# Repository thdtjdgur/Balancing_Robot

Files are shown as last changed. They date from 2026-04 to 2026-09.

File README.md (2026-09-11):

# ESP32 밸런싱로봇

<p align="center">
  
  
  
  
</p>

<p align="center">
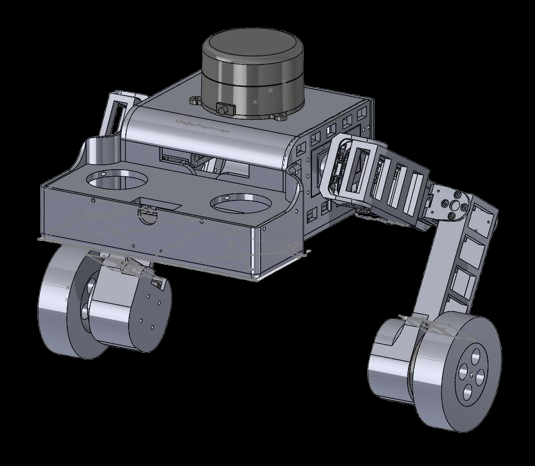
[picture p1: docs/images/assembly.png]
SolidWorks assembly render
  
</p>

`ESP32-S3` 기반 2륜 밸런싱로봇의 제어 코드와 검증 자료를 정리한 저장소이다.

기지국에서 전달한 GPS 웨이포인트를 순서대로 따라가며 사람을 수색하는 구조를 목표로 한다. 로봇은 현재 위치와 목표점을 로컬 `x/y` 좌표로 변환한다. `MPPI` 제어기는 이 좌표를 바탕으로 목표 속도와 목표 각속도를 계산한다. 이 명령은 모터에 바로 전달되지 않는다. 속도, 자세, 요 제어용 `PID`를 거친 뒤 왼쪽과 오른쪽 바퀴의 `Vq` 명령으로 나뉜다. 마지막으로 엔코더 각도를 이용한 역 DQ 변환을 통해 BLDC 3상 전압으로 출력한다.

실물 로봇을 바로 튜닝하지 않는다. MATLAB에서 MPPI 명령 생성 로직을 먼저 확인한다. 이후 `SILS`와 `HILS`로 PID 제어 흐름과 ESP32 펌웨어 통신 구조를 검증한다. 마지막 단계에서 실물 로봇으로 외란 복귀, 목표 속도 추종, 블루투스 수동 조작을 확인한다.

---

## 전체 제어 흐름

```text
기지국 GPS 웨이포인트
-> GNSS 로컬 좌표 변환
-> 웨이포인트 관리자
-> MPPI 제어기: v_ref, w_ref 생성
-> 속도 PID: 목표 피치 생성
-> 피치 PID + 요 제어: 좌우 Vq 생성
-> 엔코더 각도 보정
-> 역 DQ 변환
-> BLDC 3상 전압 출력
```

MPPI는 목표점까지 이동하기 위한 상위 명령을 만든다. PID는 로봇이 넘어지지 않도록 속도 명령을 자세 제어로 바꾼다. DQ 변환은 계산된 전압 명령을 실제 BLDC 모터가 사용할 3상 전압으로 바꾸는 단계이다.

---

## 구현 범위

- ESP32-S3 기반 밸런싱로봇 제어 루프를 구현한다.
- 기지국 GPS 웨이포인트를 순서대로 따라가는 GNSS 미션 레이어를 구성한다.
- MPPI 제어기로 목표 속도와 목표 각속도를 생성한다.
- MATLAB MPPI 시뮬레이션으로 펌웨어 적용 전 명령 생성 로직을 확인한다.
- 속도, 피치, 요 제어가 이어지는 캐스케이드 PID 구조를 구성한다.
- 엔코더 기반 속도 추정과 BLDC 3상 전압 생성을 구현한다.
- 블루투스 조이스틱 입력으로 실물 밸런싱과 수동 조작을 확인한다.
- MATLAB/Simulink HILS를 구성해 실제 ESP32 펌웨어와 가상 모델의 데이터 교환을 검증한다.
- RX-28 관절 액추에이터와 YDLIDAR G2 확장 코드를 함께 정리한다.

---

## 제어 구조

## 1. MPPI: 웨이포인트를 속도와 각속도 명령으로 바꾸는 상위 제어기

### 역할

MPPI는 현재 위치, 목표점, 장애물 정보를 받아 여러 개의 미래 명령열을 만든다. 명령열 하나는 `v_ref`와 `w_ref`의 시간 순서이다. 각 명령열을 적용했을 때 로봇이 어디로 움직일지 예측하고, 목표점에 가까우면서 장애물을 피하는 명령열에 높은 가중치를 준다.

마지막에는 모든 후보 명령열을 가중 평균한다. 실제 로봇에는 그중 첫 번째 명령만 전달한다. 다음 제어 주기에서 다시 샘플링하므로, 로봇은 매 순간 새 센서값을 반영해 경로를 다시 고른다.

### ESP32 펌웨어 구성

ESP32 쪽 MPPI 코드는 `SoftWare/Gnss_Mppi`에 들어 있다.

- `gnss.c`: 현재 GNSS 위치와 목표 웨이포인트를 로컬 `x/y` 좌표로 변환한다.
- `waypoint.c`: 기지국에서 받은 웨이포인트를 순서대로 목표점에 넣는다.
- `mppi.c`: 후보 명령열을 만들고, 예측 상태를 계산한 뒤 최종 `v_ref`, `w_ref`를 선택한다.
- `cost.c`: 목표점 오차, 장애물 거리, 입력 크기, 입력 변화량을 비용으로 계산한다.
- `lidar.c`: 라이다 거리 데이터를 받아 장애물 정보를 구성한다.

### 장애물 처리

실제 로봇은 라이다 360도를 `24`개 섹터로 나눠 본다. 한 섹터 안에 장애물이 여러 개 들어오면 가장 가까운 장애물 하나만 대표값으로 저장한다. MPPI 비용 계산에서는 이 섹터 거리와 각도를 월드 좌표의 장애물 위치로 바꾼다. 예측된 로봇 위치가 안전거리 안으로 들어가면 장애물 비용이 커진다.

MATLAB 시뮬레이션에서는 장애물을 절대좌표에 직접 배치한다. 입력 방식만 다를 뿐, 예측 로봇 위치와 장애물 위치 사이의 거리로 비용을 계산한다는 점은 같다.

### 계산 순서

1. 이전 최적 명령열을 한 칸 앞으로 당겨 현재 샘플링의 기준 명령열로 사용한다.
2. 기준 명령열에 랜덤 노이즈를 더해 후보 명령열을 만든다.
3. 후보 명령열마다 미래 로봇 위치와 방향을 예측한다.
4. 목표점 비용, 장애물 비용, 입력 비용, 입력 변화 비용을 누적한다.
5. 비용을 `exp(-(J_i - J_min) / lambda)` 형태의 MPPI 가중치로 바꾼다.
6. 가중 평균으로 최종 명령열을 만들고 첫 번째 입력만 적용한다.

### ESP32 적용 파라미터

실제 펌웨어에서는 ESP32 계산량을 고려해 짧은 예측 구간을 사용한다.

- 제어 주기: `dt = 0.1 s`
- 예측 스텝: `horizon = 6`
- 후보 명령열: `num_samples = 64`
- 속도 범위: `-0.5 m/s` ~ `0.5 m/s`
- 각속도 범위: `-1.2 rad/s` ~ `1.2 rad/s`
- MPPI 온도 파라미터: `lambda = 10.0`
- 장애물 안전거리: `0.5 m`

### MATLAB 사전검증

펌웨어에 넣기 전, MATLAB에서 같은 구조의 MPPI를 먼저 돌렸다. 하드웨어를 그대로 복제하려는 목적은 아니다. 목표점과 장애물이 있을 때 후보 명령열이 충분히 퍼지는지, 장애물 비용이 회피 방향에 영향을 주는지, 최종 가중 평균 궤적이 목표점 방향으로 이어지는지를 보기 위한 단계이다.

시뮬레이션 코드는 `SoftWare/Mppi_matlab_simulation`에 정리했다.

- `main.m`: 시작점, 목표점, 장애물, 반복 루프를 설정한다.
- `mppi/init_mppi_params.m`: MPPI 파라미터와 비용 가중치를 설정한다.
- `mppi/mppi_step.m`: 후보 명령열 생성, 비용 계산, 가중 평균 계산을 수행한다.
- `cost/calc_total_cost.m`: 목표점, 장애물, 입력, 부드러움 비용을 계산한다.
- `sim/draw_sim.m`: 로봇 이동 경로, 장애물, 목표점, 후보 궤적을 그린다.

[MPPI MATLAB 시뮬레이션 영상](docs/videos/mppi_test.mp4)

MATLAB 검증에서 사용한 주요 설정은 다음과 같다.

- 제어 주기: `dt = 0.1 s`
- 예측 스텝: `horizon = 30`
- 예측 시간: `3.0 s`
- 후보 명령열: `num_samples = 64`
- 속도 범위: `-0.5 m/s` ~ `0.5 m/s`
- 각속도 범위: `-1.2 rad/s` ~ `1.2 rad/s`
- MPPI 온도 파라미터: `lambda = 10.0`
- 이전 최적 명령열이 있을 때 노이즈: `v_amp = 0.30`, `w_amp = 0.80`
- 첫 탐색 노이즈: `v_amp = 0.40`, `w_amp = 0.90`

### 비용 함수

MATLAB 비용 함수는 아래 구조로 계산한다.

```text
total_cost =
  goal_cost
  + obstacle_cost
  + input_cost
  + smooth_cost
```

검증 당시 비용 가중치는 다음과 같다.

- 목표점 x축 가중치: `weight_goal_x = 1.5`
- 목표점 y축 가중치: `weight_goal_y = 1.5`
- 장애물 비용 가중치: `weight_obstacle = 120.0`
- 속도 입력 비용 가중치: `weight_input_v = 0.1`
- 각속도 입력 비용 가중치: `weight_input_w = 0.1`
- 속도 변화 비용 가중치: `weight_smooth_v = 0.3`
- 각속도 변화 비용 가중치: `weight_smooth_w = 0.3`
- 장애물 안전거리: `obs_safe_dist = 1.0 m`

## 2. PID: MPPI 명령을 넘어지지 않는 자세 제어로 바꾸는 층

### 역할

MPPI가 만든 `v_ref`와 `w_ref`는 모터에 바로 넣지 않는다. 밸런싱로봇은 목표 속도를 따라가면서 몸체 각도도 계속 잡아야 한다. 그래서 목표 속도는 먼저 목표 피치가 되고, 피치 제어 결과가 좌우 바퀴 전압 명령으로 이어진다.

### 제어 흐름

```text
targetvel_vel
-> 속도 PID
-> target_pitch
-> 피치 PID
-> 균형 유지용 출력
-> yaw 보정값과 합성
-> Vq_left, Vq_right
```

속도 PID는 목표 속도와 현재 속도의 차이로 몸체가 얼마나 기울어야 하는지 정한다. 피치 PID는 현재 피치가 목표 피치에 맞도록 균형 출력을 만든다. 요 제어는 왼쪽과 오른쪽 바퀴 명령에 차이를 만들어 회전 방향을 잡는다.

### SILS

SILS에서는 실제 하드웨어 없이 제어 응답을 먼저 본다. 응답이 발산하는지, 목표 속도나 외란에 대해 로봇 자세가 다시 안정되는지 확인한다.

<p align="center">
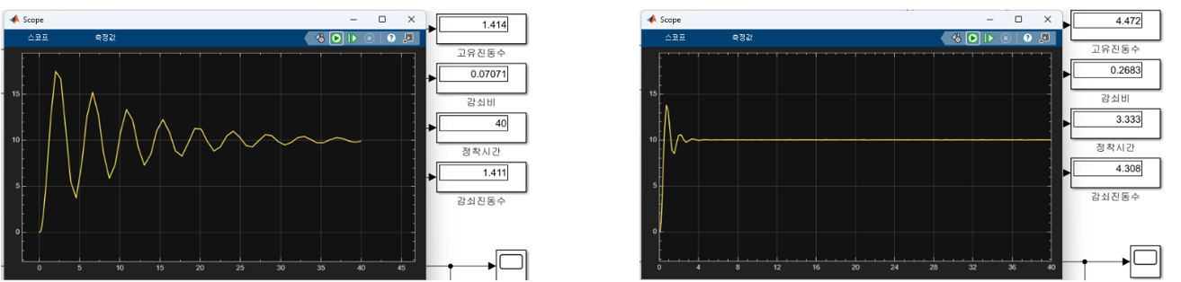
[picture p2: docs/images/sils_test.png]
SILS test result
  
</p>

### HILS 통신 구조

SILS 이후에는 HILS를 구성한다. MATLAB/Simulink가 가상 센서 역할을 하고, 실제 ESP32 펌웨어가 제어 계산을 맡는다. 실물 로봇에 올리기 전에 데이터 패킷, 제어 주기, 반환 전압값이 의도대로 이어지는지 확인하는 단계이다.

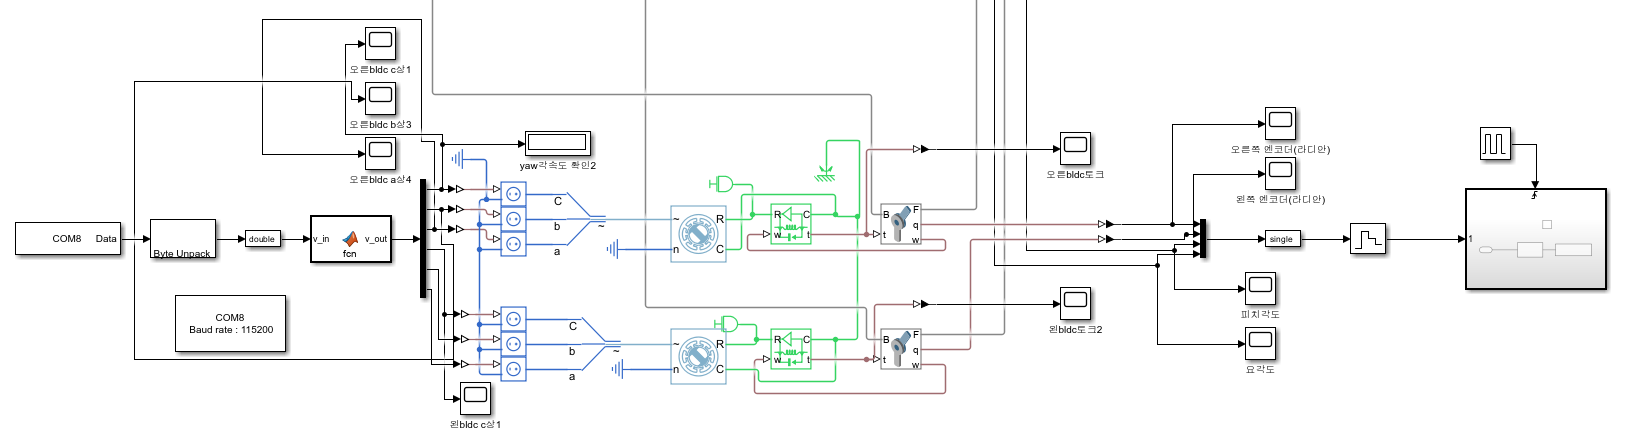
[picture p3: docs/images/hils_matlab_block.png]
HILS block diagram


PC와 ESP32는 `CP2102 USB-to-TTL` 모듈로 연결한다. ESP32는 `UART2`를 사용하고, `TX=GPIO17`, `RX=GPIO18`에 연결한다.

MATLAB에서 ESP32로 보내는 값은 오른쪽 엔코더, 왼쪽 엔코더, pitch, yaw이다. 각 값은 `single(float)`이므로 4바이트이다. 한 번 보낼 때 `4개 * 4바이트 = 16바이트`가 된다.

ESP32는 받은 센서값으로 제어를 계산하고, 왼쪽과 오른쪽 BLDC의 3상 전압을 MATLAB으로 돌려보낸다. 반환값은 총 6개 float이므로 `6개 * 4바이트 = 24바이트`이다. Simulink에서는 `Serial Receive`로 24바이트를 받고, `Byte Unpack`으로 6개의 `single(float)` 값으로 복원한다.

### 보레이트 계산

[HILS 구조 참고 PDF](docs/references/hils_flow.pdf) 기준으로 MATLAB에서 ESP32로 보내는 센서 패킷은 1kHz 주기로 들어온다.

```text
16 byte/packet * 1000 packet/s = 16000 byte/s
```

UART는 일반적으로 8비트 데이터 앞뒤에 start bit와 stop bit가 붙는다. 즉 1바이트를 보내려면 실제 라인에서는 10비트가 필요하다.

```text
16000 byte/s * 10 bit/byte = 160000 bit/s
```

ESP32에서 MATLAB으로 돌아오는 값은 24바이트 패킷이다. 같은 1kHz 기준으로 보면 아래와 같다.

```text
24 byte/packet * 1000 packet/s * 10 bit/byte = 240000 bit/s
```

양방향 모두 같은 UART 설정을 쓰므로 더 큰 쪽인 `240000 bps`보다 높은 보레이트가 필요하다. 그래서 `921600 bps`를 사용했다. 계산상 필요한 속도보다 약 3.8배 여유가 있고, HILS에서 1kHz 데이터 교환을 할 때 패킷 지연 여지를 줄일 수 있다.

### 속도 추정

엔코더 각도는 `1 kHz`로 읽지만 속도 추정은 매 주기마다 갱신하지 않는다. `1 ms` 차분에서는 각도 변화량이 너무 작다. 작은 엔코더 흔들림도 큰 속도 스파이크처럼 계산될 수 있다.

그래서 엔코더 각도는 계속 `1 kHz`로 샘플링하고, 속도 추정만 `10`회마다 한 번 갱신한다. 실제 속도 추정 주기는 `10 ms`이다. `+/-pi` 경계에서 각도 차이가 튀지 않도록 언랩 처리를 넣고, `0.5 / 0.5` 저역통과 필터로 남은 노이즈를 줄인다.

### RTOS 스케줄링

실물 로봇에서는 센서 요청과 모터 출력의 타이밍이 바로 진동으로 이어졌다. 엔코더 경로는 GPTimer `1 MHz` 해상도와 `alarm_count = 1000` 설정으로 `1 ms`마다 동작한다. SPI 엔코더 읽기가 끝나면 `spi_post_callback()`에서 `encoder_sem`을 깨운다. `motor_control_task`는 새 엔코더 값이 준비됐을 때만 모터 전압 계산을 수행한다.

IMU 경로는 `IMU_ALARM_COUNT = 5000`으로 `5 ms`, 즉 `200 Hz`마다 동작한다. 모터 제어 태스크는 우선순위 `5`, RX-28 태스크는 우선순위 `4`로 분리한다. 엔코더 기반 모터 출력 경로를 더 높은 우선순위로 두면서 균형 제어의 시간 흔들림을 줄인다.

### 조이스틱 입력

블루투스 조이스틱 입력은 자동 수색 미션의 주 경로가 아니라 실물 밸런싱 테스트용 입력이다. `hc06.c`는 `S,x,y,diff,E` 형식의 패킷을 파싱한다. 조이스틱이 중앙 근처에 있으면 목표 속도와 요 명령을 0으로 만든다. 일정 크기 이상 움직이면 전진 속도와 회전 명령을 생성한다.

이 입력으로 실물 로봇이 넘어지지 않고 전진, 정지, 회전을 수행하는지 확인한다.

### RX-28 관절 제어

RX-28 관절 제어는 카메라 흔들림을 줄이기 위한 확장 구조이다. IMU에서 측정한 `roll` 값을 기준으로 보정 길이 `roll_adj_mm`를 만든다. 좌우 다리 높이를 다르게 계산해 골반과 무릎 RX-28 목표 위치로 변환한다.

`rx28.c`는 미리 계산한 다리 높이 테이블을 이용해 목표 높이에 맞는 관절 값을 보간한다. 바퀴 제어만으로 처리하기 어려운 좌우 기울어짐을 관절 쪽에서 보정하는 구조이다.

## 3. DQ 변환: Vq 명령을 BLDC 3상 전압으로 바꾸는 층

### 역할

PID를 거쳐 나온 최종 명령은 왼쪽과 오른쪽 바퀴의 `Vq_left`, `Vq_right`이다. 이 값은 BLDC 모터의 q축 전압 명령이다. 실제 모터에는 3상 전압 `Va`, `Vb`, `Vc`가 들어가야 한다. 그래서 엔코더 각도를 이용해 역 Park 변환과 Clarke 변환을 수행한다.

### SPI 타이밍 문제

DQ 변환에서 가장 먼저 맞춰야 했던 값은 엔코더 각도이다. AS5048A 엔코더는 SPI로 16비트 데이터를 보낸다. 이때 CSn을 낮춘 뒤 첫 번째 클럭 상승까지 필요한 최소 시간이 데이터시트 기준 `tL = 350 ns`이다.

<p align="center">
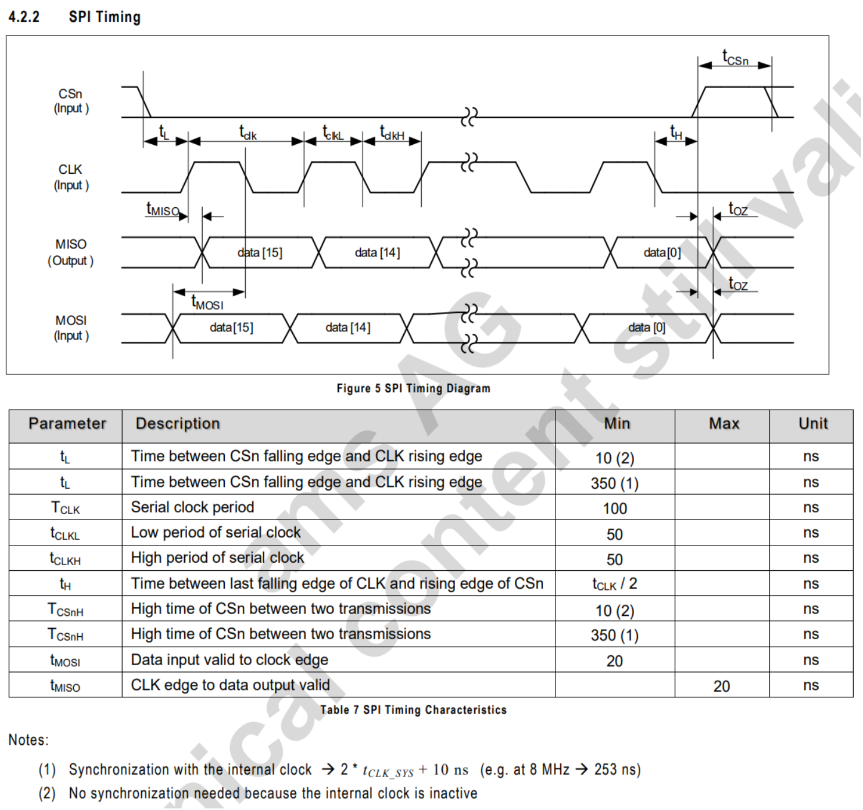
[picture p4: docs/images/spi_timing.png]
AS5048A SPI timing
  
</p>

초기에는 CSn을 낮춘 직후 바로 데이터를 읽으면서 16비트 저장 위치가 한 칸씩 밀렸다. 첫 번째 클럭이 아직 생성되기 전인데 MCU가 `data[15]` 자리를 읽으려 하면, 그 위치에는 유효한 센서 데이터가 들어오지 않는다. 결과적으로 15번째 비트에는 의미 없는 값이 들어가고, 14번째 비트에는 원래 `data15`, 13번째 비트에는 원래 `data14`가 들어가는 식으로 데이터가 오른쪽으로 밀린다.

MCU는 하위 14비트를 각도 원시값으로 해석한다. 당시에는 에러 비트가 항상 1처럼 보였고, 밀린 데이터 때문에 각도 원시값의 상위 비트가 계속 켜지는 현상이 발생했다. 그 결과 각도값에 180도가 더해진 것처럼 해석되어 `180~360 deg` 구간 위주로 값이 나왔다.

해결은 CSn 이후 첫 클럭까지의 대기 시간을 SPI 설정으로 보장하는 방식이다. 현재 엔코더 SPI 클럭은 `10 MHz`이고, 한 클럭은 `100 ns`이다. `encoder.c`에서 `.cs_ena_pretrans = 4`로 설정해 약 `400 ns`를 기다린다. 이 값은 필요한 `350 ns`보다 길기 때문에 첫 번째 클럭 전에 데이터가 밀리는 문제를 줄인다.

### 전기각 오프셋

엔코더 각도는 전기각 오프셋도 맞춰야 한다. `d = 상수`, `q = 0`으로 두면 토크를 만드는 q축 명령은 0이 된다. 대신 회전자를 고정시키는 d축 성분이 상수로 들어가므로 회전자가 한 위치에 고정된다. 이때의 엔코더 값은 전기적 각도 0도에 해당하는 기계적 기준값이다. 이 값이 오프셋이다.

엔코더가 그 순간 0을 읽는 것은 아니다. 그래서 실제 제어에서는 읽어온 엔코더 각도에서 오프셋 각도를 뺀 뒤 극쌍수를 곱해 전기각을 계산한다.

```text
electrical_angle = (measured_encoder_angle - offset_angle) * pole_pairs
```

현재 코드에서는 `GM4108H-120T` 모터의 극쌍수 `11`을 사용한다. 왼쪽 바퀴 오프셋은 `2.7756 rad`, 오른쪽 바퀴 오프셋은 `1.6345 rad`이다.

### 3상 전압 생성

전기각을 계산한 뒤 `Vd = 0`, `Vq = Vq_left/right`를 기준으로 역 Park 변환을 수행한다. 이후 Clarke 변환으로 `Va`, `Vb`, `Vc`를 만든다. 이 3상 전압이 MCPWM 출력으로 전달되어 BLDC 모터를 구동한다.

---

## 실물 테스트

HILS 이후에는 실물 로봇으로 외란 복귀, 위치 유지, 블루투스 주행을 확인한다. 이 단계에서는 제어 알고리즘 자체뿐 아니라 태스크 우선순위, 엔코더 속도 추정 주기, 조이스틱 입력이 실제 균형 유지에 어떤 영향을 주는지 함께 확인한다.

<p align="center">
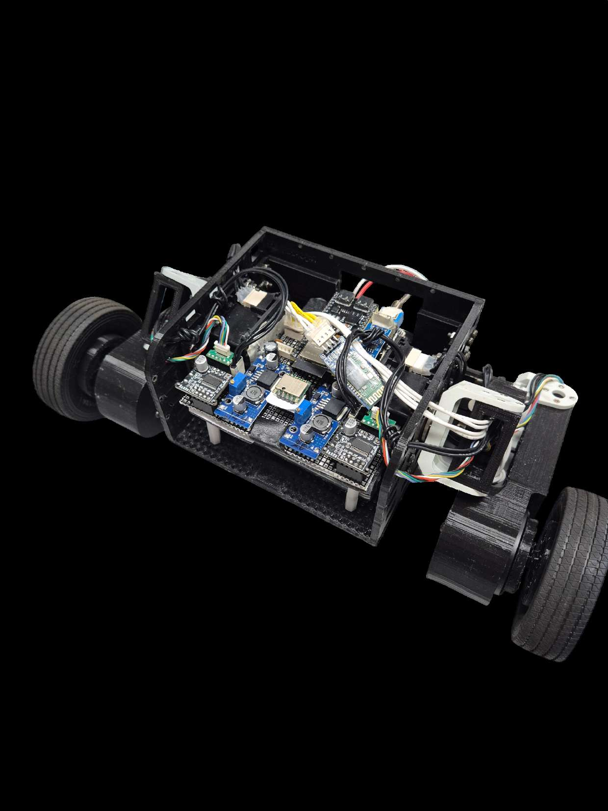
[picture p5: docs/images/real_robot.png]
real robot
  
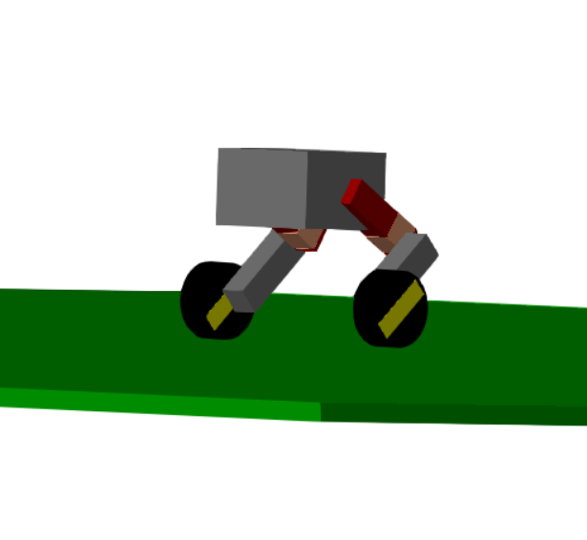
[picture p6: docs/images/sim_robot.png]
simulation robot
  
</p>

실물 테스트에서 중점적으로 보는 항목은 다음과 같다.

- 외부에서 밀었을 때 로봇이 다시 자세를 회복하는지 확인한다.
- 목표 속도를 줄 때 몸체가 자연스럽게 기울어지며 따라가는지 확인한다.
- 블루투스 조이스틱으로 전진, 정지, 회전을 입력해도 밸런싱이 깨지지 않는지 확인한다.

---

## 검증 자료

GitHub README에서는 mp4가 항상 바로 재생되지 않기 때문에 영상은 링크로 정리한다.

- [MPPI MATLAB 시뮬레이션](docs/videos/mppi_test.mp4)
- [HILS 테스트 영상](docs/videos/hils_test.mp4)
- [SILS yaw 테스트 영상](docs/videos/sils_yaw_test.mp4)
- [SILS 목표 속도 테스트 영상](docs/videos/sils_target_velocity_test.mp4)
- [SILS 외란 복귀 테스트](docs/videos/sils_disturbance_rejection.mp4)
- [실물 외란 복귀 테스트](docs/videos/real_world_disturbance_rejection.mp4)
- [실물 위치 유지 테스트](docs/videos/real_world_hold_position_after_disturbance.mp4)
- [실물 블루투스 조작 테스트](docs/videos/real_world_bluetooth_control.mp4)
- [BLDC 역 DQ 제어 영상 Q=1](docs/videos/inverse_dq_control_q1.mp4)
- [BLDC 역 DQ 제어 영상 Q=4](docs/videos/inverse_dq_control_q4.mp4)
- [HILS 구조 참고 PDF](docs/references/hils_flow.pdf)
- [밸런싱로봇 정리 PDF](docs/images/balancing_robot_evidence.pdf)

---

## 하드웨어 구성

최종 실물 테스트 기준 주요 부품은 다음과 같다.

- 메인 컨트롤러: `ESP32-S3-WROOM-1 N16R8`
- 휠 모터: `GM4108H-120T` BLDC 모터 2개
- 휠 모터 드라이버: `MKS SimpleFOC MINI` 2개
- 휠 엔코더: `AS5048A` 2개
- 관절 액추에이터: `Dynamixel RX-28` 4개
- 통신 변환기: `MAX485 TTL to RS-485`
- IMU: `WT901`
- 블루투스 모듈: `HC-06`
- HILS UART 브리지: `CP2102 USB-to-TTL`
- 전원: `3S LiPo battery`, `XL6009` 승압 모듈

검토 또는 확장용으로 사용한 부품은 다음과 같다.

- `U2D2`
- `U2D2 Power Hub`
- `YDLIDAR G2`
- `MPU6050`

최종 밸런싱 테스트에서 실제로 사용한 IMU는 `WT901`이다.

---

## 파일 구조

- `SoftWare/Physical_operation_code/`: 실물 밸런싱로봇용 ESP-IDF 펌웨어이다.
- `SoftWare/Physical_operation_code/app_main.c`: 태스크 생성, 세마포어 대기, PID 제어 통합을 담당한다.
- `SoftWare/Physical_operation_code/encoder.c`: 엔코더 SPI 읽기, 속도 추정, 전기각 계산, 역 DQ 변환, 3상 전압 출력을 담당한다.
- `SoftWare/Physical_operation_code/imu.c`: WT901 IMU 값을 읽고 200 Hz 상태 갱신 경로를 구성한다.
- `SoftWare/Physical_operation_code/pid.c`: 속도, 피치, 요, 롤 제어에 사용하는 PID 계산을 담당한다.
- `SoftWare/Physical_operation_code/pwm.c`: MCPWM 기반 모터 전압 출력을 담당한다.
- `SoftWare/Physical_operation_code/hc06.c`: 블루투스 조이스틱 입력을 파싱한다.
- `SoftWare/Physical_operation_code/rx28.c`: RX-28 관절 제어와 roll 기반 보정 구조를 담당한다.
- `SoftWare/Physical_operation_code/lidar.c`: YDLIDAR G2 확장 코드를 포함한다.
- `SoftWare/Gnss_Mppi/`: GNSS 웨이포인트, 24섹터 라이다 장애물, MPPI 명령 생성이 포함된 펌웨어 변형이다.
- `SoftWare/Mppi_matlab_simulation/`: ESP32 MPPI 적용 전 MATLAB에서 명령 생성 로직을 검증한 코드이다.
- `SoftWare/hils_test_code/`: MATLAB/Simulink HILS 검증용 ESP-IDF 프로젝트이다.

---

## 빌드 방법

이 프로젝트는 `ESP-IDF` 기준으로 작성한다.

실물 로봇 코드는 `SoftWare/Physical_operation_code`에서 빌드한다.

```bash
idf.py build
```

보드에 플래시한다.

```bash
idf.py -p (PORT) flash
```

필요하면 시리얼 모니터를 연다.

```bash
idf.py -p (PORT) monitor
```

HILS용 코드를 사용할 때는 `SoftWare/hils_test_code`로 이동한 뒤 같은 `idf.py` 흐름을 사용한다. GNSS와 MPPI가 포함된 자율 주행용 코드는 `SoftWare/Gnss_Mppi`에서 확인한다.

---

## 한 줄 요약

GPS 웨이포인트 기반 수색 로봇을 만들기 위해 MPPI로 상위 이동 명령을 만들고, PID로 균형을 유지하며, 엔코더 보정 기반 역 DQ 변환으로 BLDC 모터를 구동한 ESP32 밸런싱로봇 프로젝트이다.

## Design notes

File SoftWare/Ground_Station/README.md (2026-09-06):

# Drone GUI Ground Station

`guitest.py`는 지도/웨이포인트 UI를 제공하고, `keytest.py`는 NTRIP 수신과
TTGO 시리얼 링크의 2초 반이중 송신 주기를 관리합니다.

## RTCM 정책

- 허용 타입: `1004`, `1006`, `1012`, `1230`
- 타입마다 최신 정상 프레임 하나만 보관
- 동일 타입의 새 프레임은 이전 미전송 프레임을 교체
- 2초마다 신선한 `1004`, `1006`, `1012`, `1230`을 같은 cycle에 순서대로 전달
- 각 타입은 개별 stale/missing 판정하며 한 타입 문제로 전체 세트를 버리지 않음
- 오래된 프레임은 폐기하고 이미 전송한 프레임은 재전송하지 않음
- Waypoint가 대기 중이면 같은 cycle에서 RTCM 다음에 전달
- 마지막 `FF F5`를 받은 TTGO가 LoRa `A3(DOWNLINK_END)`를 송신하고 RX로 전환
- 드론은 A3에서 최신 GGA를 기존 `FE/seq/F3/len/lat/lon/det/count`로 한 번 역송신

## 실행

Python 3.9 이상에서 의존성을 설치합니다.

```powershell
python -m pip install -r requirements.txt
```

실제 계정과 API 키는 저장소에 넣지 말고 환경변수로 지정합니다.

```powershell
$env:NTRIP_USER = "your-account"
$env:NTRIP_PASSWORD = "your-password"
$env:VWORLD_API_KEY = "your-vworld-api-key"
$env:GCS_TTGO_PORT = "COM8"
python guitest.py
```

필요한 환경변수 목록은 `.env.example`을 참고하세요. 프로그램이 `.env`를
자동으로 읽지는 않으므로 PowerShell, VS Code 실행 설정 또는 운영체제 환경변수로
설정해야 합니다.

## 주요 로그

```text
[RTCM] filter pass types=1004,1006,1012,1230
[CYCLE N] RTCM set: 1004,1006,1012,1230
[CYCLE N] RTCM set sent: 1004,1006,1012,1230
[CYCLE N] DOWNLINK_END sent -> RX
[GPS RX] lat=..., lon=..., seq=..., det=..., count=...
[GUI] position updated: lat=..., lon=...
```

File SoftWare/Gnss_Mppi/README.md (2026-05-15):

# ESP32 Self-Balancing Robot with HILS, SILS, and Real-World Validation

This repository contains the ESP-IDF firmware for a two-wheeled self-balancing robot. The project was validated in three stages: HILS (Hardware-in-the-Loop Simulation) for communication and control-chain verification, SILS (Software-in-the-Loop Simulation) for controller behavior checks, and physical-world testing for disturbance rejection and Bluetooth driving.

---

## Features

- **Cascaded balance control**: The firmware converts target velocity into target pitch, then converts target pitch into motor q-axis voltage for upright balancing.
- **Differential yaw control**: Steering is injected as a bounded left/right voltage difference without breaking the main balance loop.
- **Real-time sensing and actuation**: The IMU loop runs at 200 Hz while the encoder and motor commutation path runs at 1 kHz.
- **MATLAB/Simulink HILS workflow**: The project includes a documented serial-based HILS pipeline for testing the control chain before full hardware deployment.
- **Wireless command input**: An HC-06 Bluetooth module is used to receive joystick commands and translate them into velocity and yaw references.
- **Exact hardware stack**: The final build uses dual GM4108H-120T BLDC wheel motors, dual MKS SimpleFOC MINI driver boards, four Dynamixel RX-28 actuators, an ESP32-S3-WROOM-1 N16R8 controller, WT901 IMU, AS5048A magnetic encoders, MAX485, XL6009 converters, and a 3S LiPo battery.

---

## System Design & Control Logic

### 1. Main balance loop

The control loop is split across two timing domains. `imu_timer_init()` starts the 200 Hz IMU update cycle, and `imu_data_cal()` refreshes `current_pitch`, `current_yaw`, and `current_roll`. In parallel, `encoder_timer_init()` starts the 1 kHz encoder path, and `motor_control_task()` wakes on the encoder semaphore to execute `encoder_to_vcc_cal()`.

Inside `app_main.c`, the outer velocity loop converts `targetvel_vel` into `target_pitch`. That target is smoothed before being passed into the pitch loop, which reduces oscillation when speed commands change. A separate yaw command is turned into a bounded differential term, then mixed with the pitch output to produce `Vq_left` and `Vq_right`.

Inside `encoder.c`, the motor-side loop reconstructs left and right encoder angles, estimates wheel speed, converts the q-axis voltages into electrical angles, and finally generates six phase voltages for the two BLDC motors. Those voltages are applied through `mcpwm_set_voltage()` in `pwm.c`.

### 2. Command input path

`hc06.c` receives joystick packets in the `S,x,y,diff,E` format over UART2. The parser recenters the joystick coordinates, suppresses small steering noise with a deadband, and maps the joystick magnitude to either a stop command or a forward velocity target. This keeps wireless control simple while still exercising the real balance and steering logic.

### 3. Additional hardware support

`rx28.c` runs a dedicated FreeRTOS task for four Dynamixel RX-28 actuators through a MAX485 TTL-to-RS-485 link. `lidar.c` contains experimental YDLIDAR G2 support, and `hc06.c` handles Bluetooth joystick commands over UART. `variable.h` also already reserves HILS-oriented shared variables such as `hils_angle_l`, `hils_angle_r`, `hils_pitch`, `hils_yaw`, and `hils_v_out[6]`, making it easier to extend the MATLAB integration further.

---

## Demonstration Videos

GitHub does not reliably inline-play repository `mp4` files inside `README.md`, so the videos below are linked directly.

### 1. HILS test

[Open HILS test video](assets/videos/hils_test.mp4)

[HILS communication flow reference](assets/docs/hils_flow.pdf)

This video shows the control pipeline running in a Hardware-in-the-Loop setup before applying the algorithm to the physical robot. According to the HILS flow document, MATLAB/Simulink sends four `single` values every 1 ms: left encoder angle, right encoder angle, pitch, and yaw. That becomes a 16-byte packet from MATLAB to ESP32. The same document explains why `921600 bps` was used for the serial link: even after accounting for UART start and stop bits, the receive side only needs about `160 kbps`, so the link has enough margin for stable round-trip communication.

The flow document also shows the physical HILS wiring: a CP2102 USB-to-TTL module is connected to ESP32 UART2 on pins TX17 and RX18. On the control side, the HILS loop mirrors the real firmware structure. The 200 Hz balance update generates `Vq_left` and `Vq_right` from the cascaded velocity and pitch logic, and the 1 kHz motor-side loop expands those values into six phase voltages for the left and right BLDC motors. The HILS return path is described as six `float` phase voltages packed into a 24-byte packet, which matches the six-voltage structure produced by the firmware in `encoder.c`.

### 2. SILS yaw test

[Open SILS yaw test video](assets/videos/sils_yaw_test.mp4)

This video isolates the yaw branch of the controller. In `app_main.c`, the yaw command does not replace the balance loop. Instead, it is converted into a bounded turning term and added to the left motor while being subtracted from the right motor. Because steering is implemented as a differential overlay on top of the pitch output, the test is useful for checking whether the robot can rotate without collapsing the balance controller.

### 3. SILS target velocity test

[Open SILS target velocity test video](assets/videos/sils_target_velocity_test.mp4)

This test focuses on the outer velocity loop. In `encoder.c`, wheel speed is estimated from encoder angle differences every 10 ms, angle wraparound is corrected, and a light low-pass filter is applied before the result is stored in `current_vel`. When a fresh speed estimate is ready, `app_main.c` uses `vel_ctrl` to convert target velocity into target pitch and smooths that pitch target once more before the balance loop uses it. The video shows that the controller responds to a speed command by changing body lean first instead of applying abrupt torque changes.

### 4. Physical world: external disturbance rejection

[Open physical-world disturbance rejection video](assets/videos/real_world_disturbance_rejection.mp4)

This video demonstrates short-push recovery in the real robot. The recovery behavior comes from the fast pitch loop in `app_main.c` together with the 1 kHz encoder-driven motor update in `encoder.c`. Because the firmware keeps recalculating motor phase voltages from the updated chassis state, the robot can reject brief disturbances and recover to an upright posture quickly.

### 5. Physical world: external disturbance hold position

[Open physical-world hold-position video](assets/videos/real_world_hold_position_after_disturbance.mp4)

This test is slightly different from simple fall recovery. Here the important point is that the robot reduces residual drift after being disturbed. When `targetvel_vel` is zero, the velocity feedback path works to pull the motion back toward a stationary state, while the pitch loop keeps the chassis upright during the same recovery sequence.

### 6. Physical world: Bluetooth teleoperation

[Open physical-world Bluetooth teleoperation video](assets/videos/real_world_bluetooth_control.mp4)

This video maps directly to the HC-06 command parser in `hc06.c`. The firmware reads packets in the `S,x,y,diff,E` format, converts joystick coordinates into centered values, removes small steering noise with deadbands, and maps larger joystick magnitude into a forward velocity command. `app_main.c` then combines that velocity target with yaw mixing to generate separate left and right motor voltages, allowing the robot to drive and steer without giving up self-balancing behavior.

---

## Hardware Components

This project uses the following modules in the final hardware stack:

- **Main controller**: ESP32-S3-WROOM-1 N16R8
- **Wheel motors**: GM4108H-120T BLDC motors x2
- **Wheel motor drivers**: MKS SimpleFOC MINI BLDC motor driver boards x2
- **Wheel encoders**: AS5048A magnetic SPI encoders x2
- **Leg actuators**: Dynamixel RX-28 x4
- **Servo bus interface**: MAX485 TTL-to-RS-485 converter module
- **IMU sensor**: WT901
- **Wireless control**: HC-06 Bluetooth UART module
- **HILS serial bridge**: CP2102 USB-to-TTL module
- **Power**: 3S LiPo battery and XL6009 boost converters

Additional lab and expansion modules referenced in the project:

- **Dynamixel test interface**: U2D2 and U2D2 Power Hub
- **Optional ranging module**: YDLIDAR G2 support exists in firmware
- **Not used in final build**: MPU6050 was evaluated but replaced by WT901

---

## Software & Setup

This firmware is developed using the Espressif IoT Development Framework (ESP-IDF).

### Prerequisites

- A working installation of the ESP-IDF toolchain
- For HILS, a MATLAB/Simulink environment configured for serial communication

### Build and flash

1. Navigate to the project root directory.
2. Open an ESP-IDF command prompt.
3. Build the project:

```bash
idf.py build
```

4. Flash the firmware to the ESP32:

```bash
idf.py -p (PORT) flash
```

5. Open the serial monitor if needed:

```bash
idf.py -p (PORT) monitor
```

---

## Project Structure

| File | Description |
| :--- | :--- |
| `app_main.c` | Main application entry point. Initializes the control loops, tasks, and shared state. |
| `pid.c` / `pid.h` | PID controller implementation used by the velocity and pitch loops. |
| `imu.c` / `imu.h` | WT901 initialization, timer scheduling, and attitude data acquisition. |
| `encoder.c` / `encoder.h` | Encoder acquisition, velocity estimation, and motor phase-voltage generation. |
| `pwm.c` / `pwm.h` | Low-level MCPWM voltage application for the six motor phases. |
| `hc06.c` / `hc06.h` | Bluetooth command input and parsing logic. |
| `rx28.c` / `rx28.h` | RX-28 leg actuator control task and interpolation logic. |
| `lidar.c` / `lidar.h` | LiDAR UART interface for future sensing extensions. |
| `variable.h` | Shared constants, globals, and cross-module control variables. |

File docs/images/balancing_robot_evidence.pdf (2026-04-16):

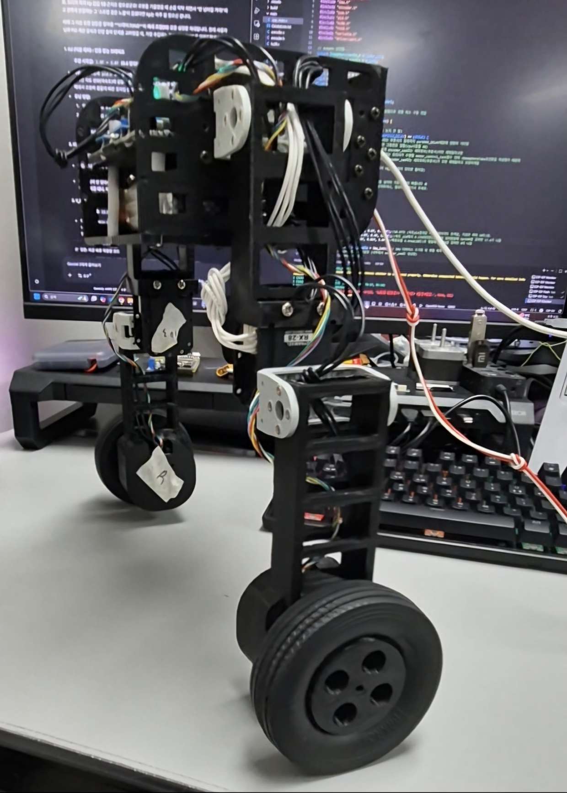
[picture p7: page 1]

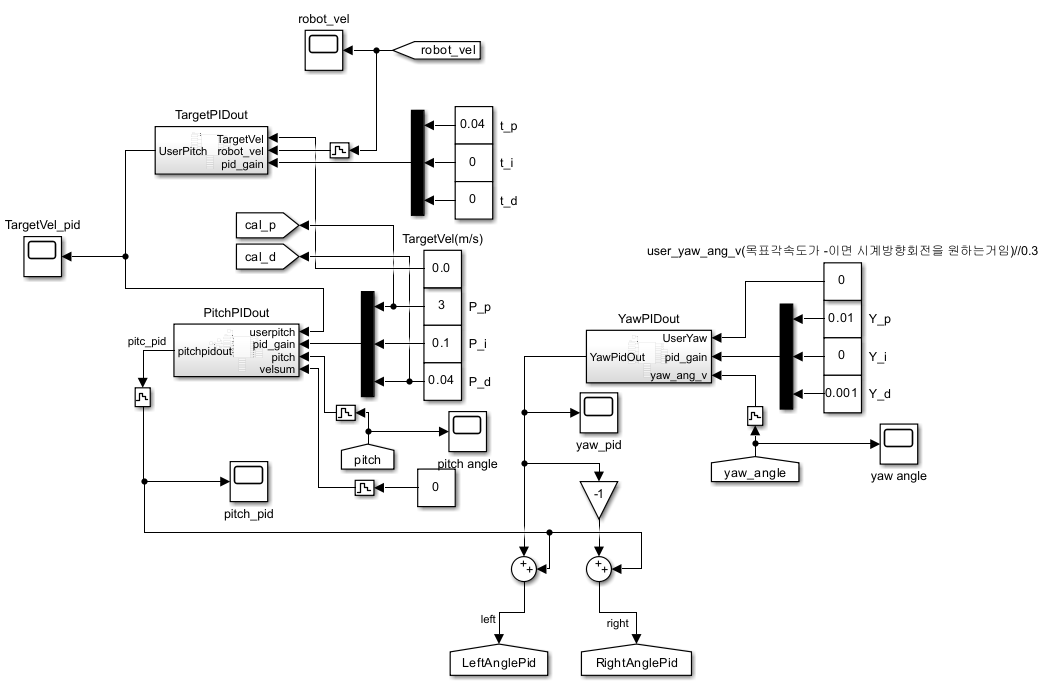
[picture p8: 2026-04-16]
docs/images/angle_controller.png

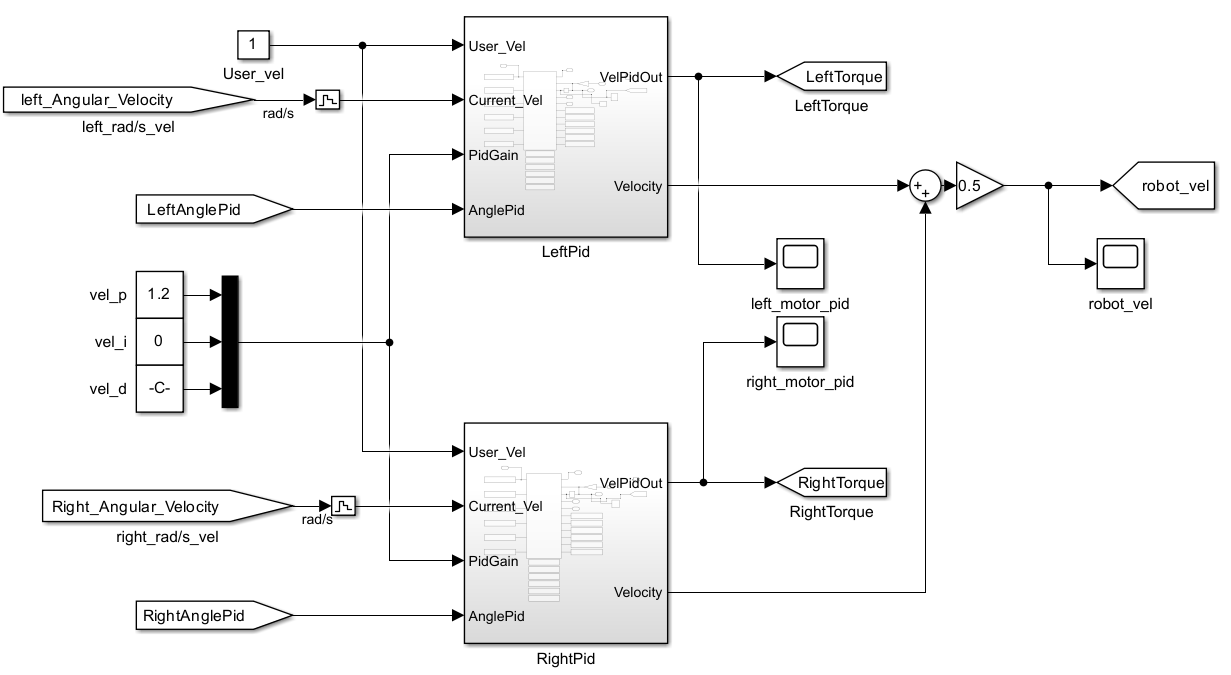
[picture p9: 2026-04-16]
docs/images/motor_controller.png

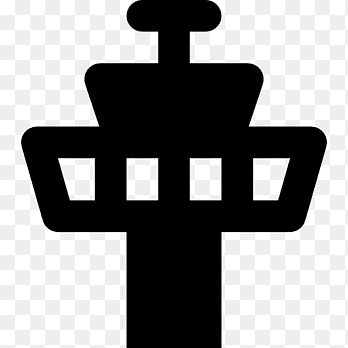
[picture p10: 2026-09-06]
SoftWare/Ground_Station/TOWER.png

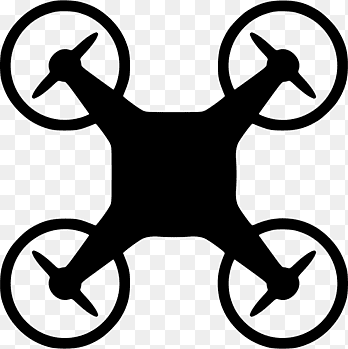
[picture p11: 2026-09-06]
SoftWare/Ground_Station/DRONE.png

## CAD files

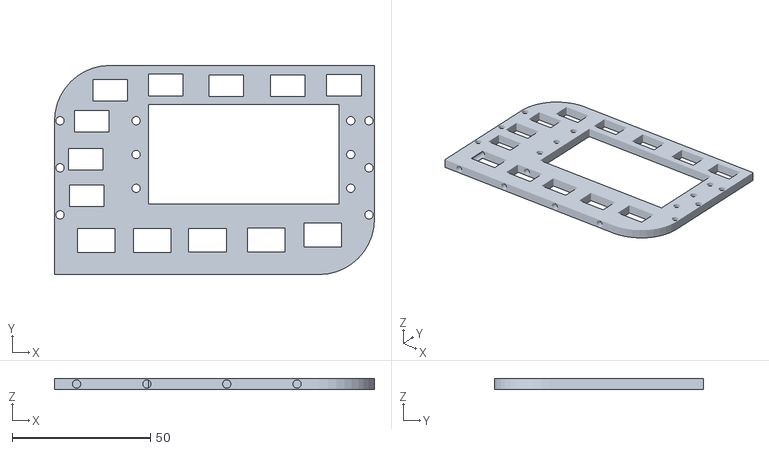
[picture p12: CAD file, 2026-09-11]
HardWare/로봇옆면.STL
115.7 x 75.6 x 4.00

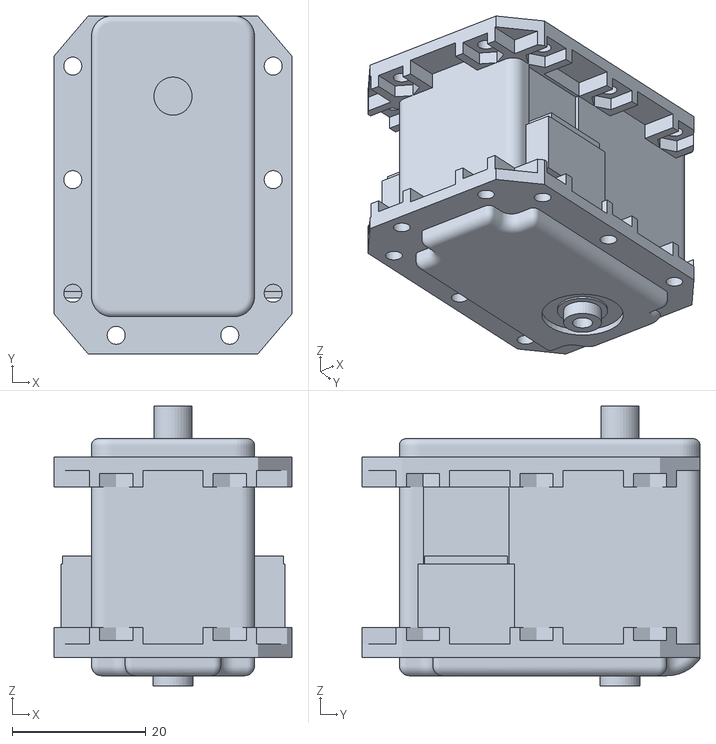
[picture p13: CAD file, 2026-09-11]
HardWare/RX-28.STL
35.6 x 50.6 x 41.9

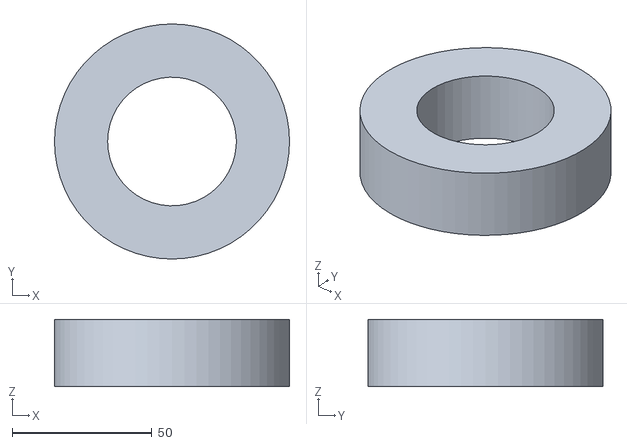
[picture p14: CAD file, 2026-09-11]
HardWare/타이어.STL
84.0 x 84.0 x 24.0

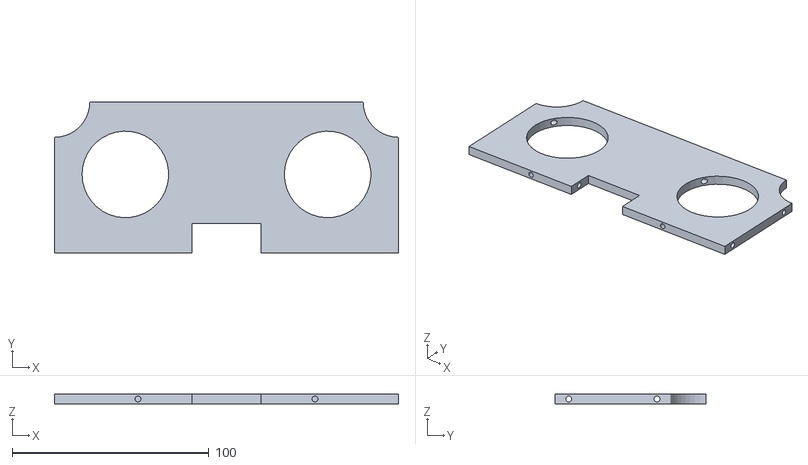
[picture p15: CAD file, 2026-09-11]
HardWare/안테나 덮개.STL
174.9 x 76.8 x 5.00

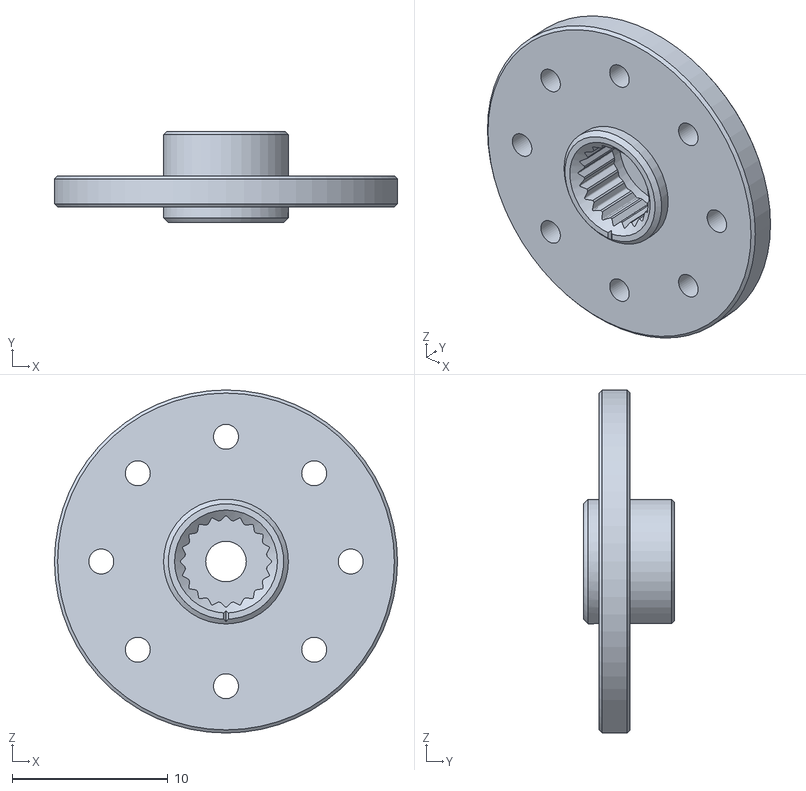
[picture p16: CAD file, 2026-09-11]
HardWare/HN07-N101.STL
22.0 x 5.85 x 22.0

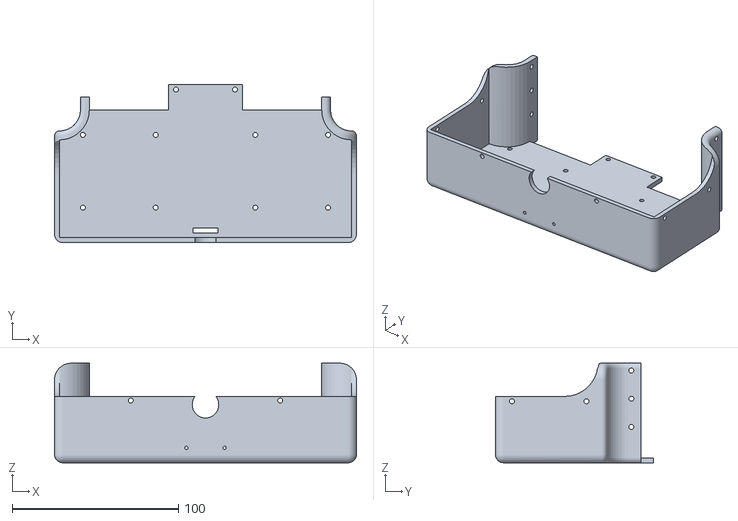
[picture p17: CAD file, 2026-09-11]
HardWare/안테나 밑면.STL
181.9 x 95.3 x 60.0

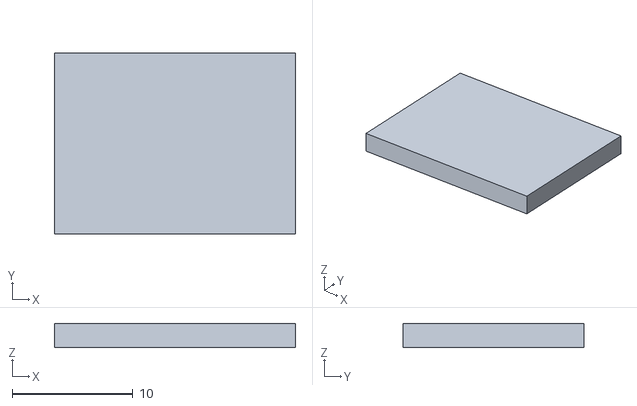
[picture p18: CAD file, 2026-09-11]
HardWare/imu.STL
20.0 x 15.0 x 2.00

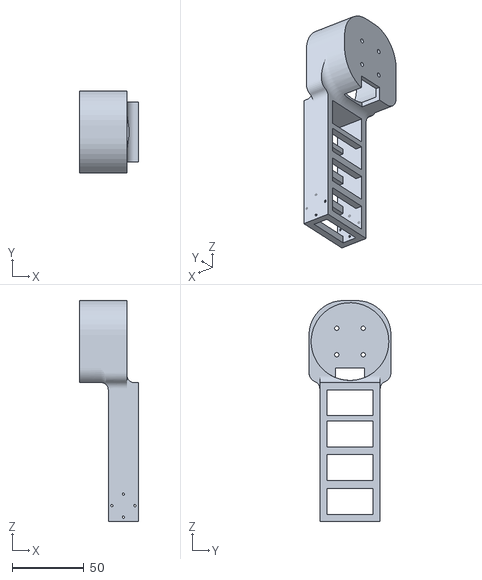
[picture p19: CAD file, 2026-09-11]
HardWare/무릎-모터.STL
41.0 x 57.0 x 153.5

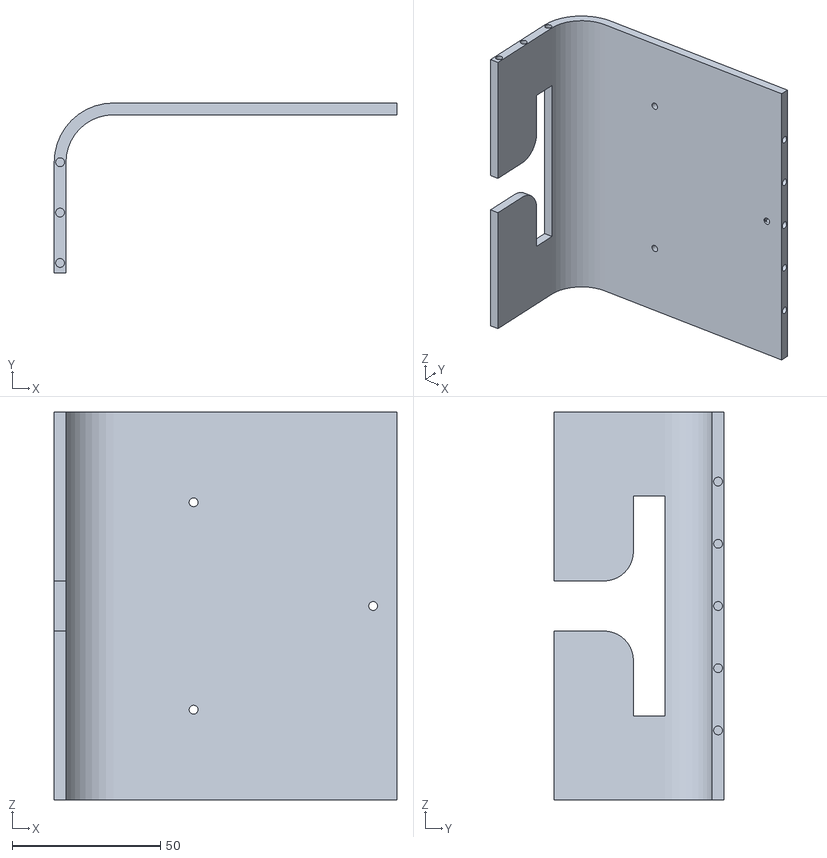
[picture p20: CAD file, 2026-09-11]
HardWare/로봇앞면 - 복사본.STL
115.7 x 57.4 x 131.0

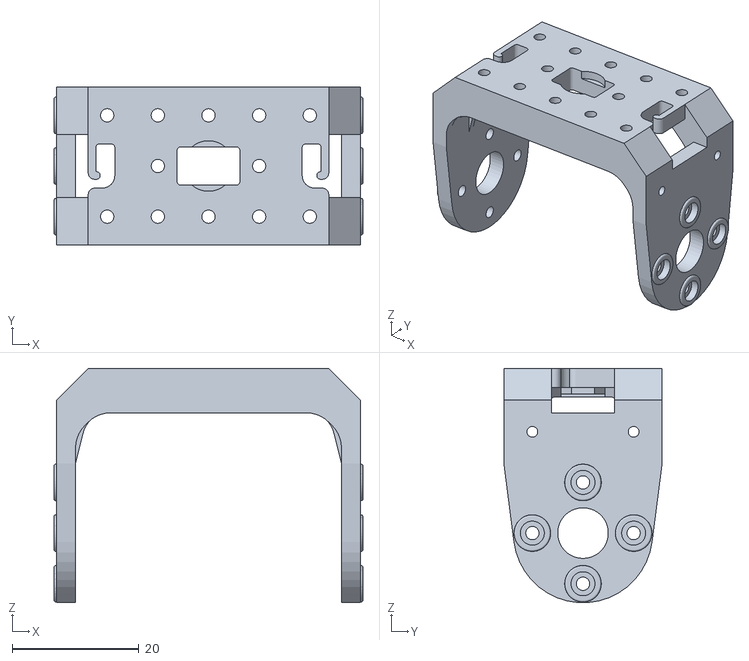
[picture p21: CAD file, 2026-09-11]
HardWare/FP04-F2.STL
48.8 x 25.0 x 37.0

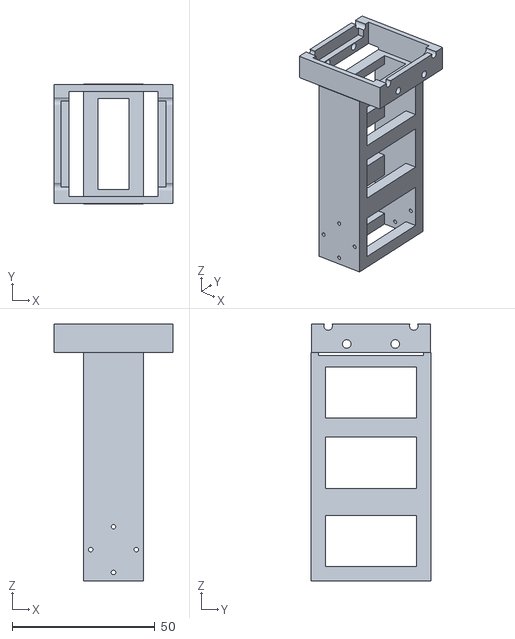
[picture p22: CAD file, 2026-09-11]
HardWare/몸체-무릎.STL
41.5 x 42.0 x 90.0

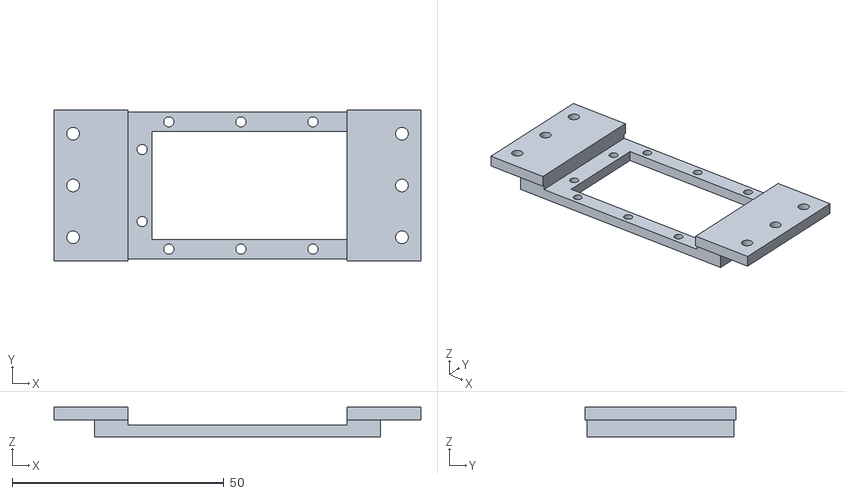
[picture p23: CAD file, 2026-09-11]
HardWare/RX-28고정부.STL
86.6 x 35.6 x 7.00

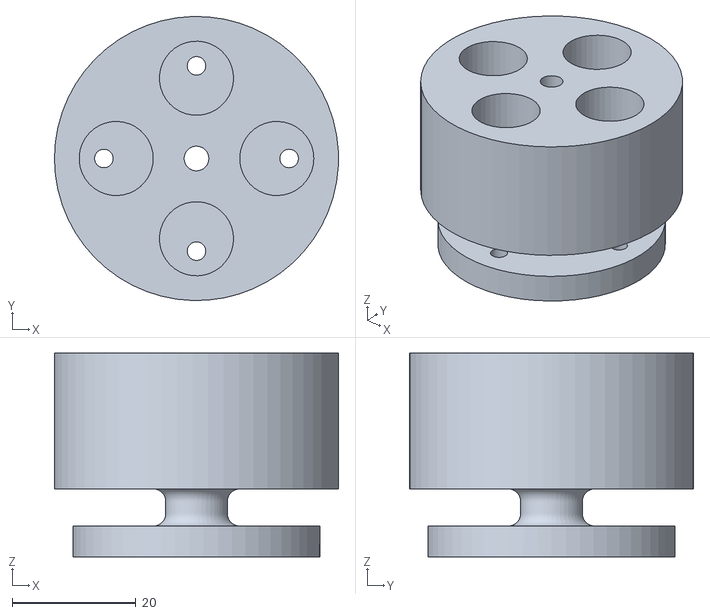
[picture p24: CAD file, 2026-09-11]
HardWare/모터-타이어 연결.STL
46.0 x 46.0 x 33.0

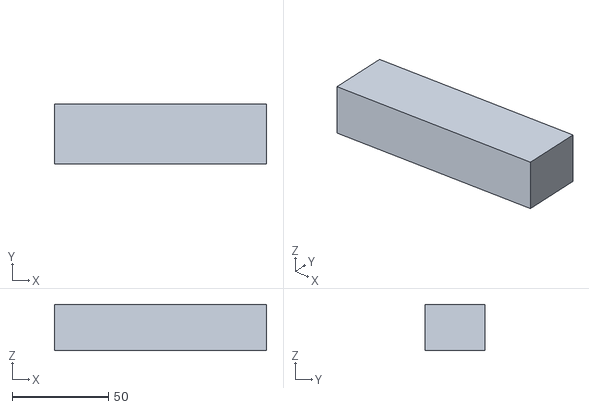
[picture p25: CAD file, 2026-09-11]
HardWare/배터리.STL
110.0 x 31.0 x 24.0

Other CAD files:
HardWare/로봇밑면.STL
HardWare/YDLidar G2.STL
HardWare/rx-28작은 원판.STL
HardWare/GM4108Motor_AS5048AEncoder_simplified.STL
HardWare/로봇뒷면.STL
HardWare/로봇앞면.STL
HardWare/몸체-무릎2.STL

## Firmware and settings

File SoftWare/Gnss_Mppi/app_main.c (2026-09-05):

#include "freertos/FreeRTOS.h"
#include "freertos/task.h"
#include "freertos/semphr.h"
#include "imu.h"
#include "encoder.h"
#include "pwm.h"
#include "pid.h"
#include "hc06.h"
#include "rx28.h"
#include "variable.h"
#include "driver/uart.h"
#include "lidar.h"
#include "MPPI.h"
#include "gnss.h"
#include "waypoint.h"
#include "lorartk.h"
#include "driver/gpio.h"
#include "esp_log.h"
#include <math.h>

// extern 선언들
extern SemaphoreHandle_t encoder_sem;
extern spi_device_handle_t h_left;
extern spi_transaction_t *ret_t;

float current_vel = 0.0f;
float current_pitch = 0.0f;
float current_yaw = 0.0f;
float current_roll = 0.0f;
float gyro = 0.0f;

float roll_adj_mm = 0.0f;
float targetvel_vel = 0.0f;    
float target_yaw_diff = 0.0f;   
int vel_calc_flag;

float omega_l_meas = 0.0f;
float omega_r_meas = 0.0f;

// PID 제어기 및 전압 변수 선언
PIDController pitch_ctrl, vel_ctrl, roll_ctrl, yaw_ctrl, wheel_l_ctrl, wheel_r_ctrl;
float Vq_left = 0, Vq_right = 0;
const float MOTOR_V_MIN = 0.0f;//1.5 // 실험으로 찾을 최소 구동 전압


static volatile int station_packet_ready = 0;
static int station_packet_len = 0;
static float station_packet[1 + (MAX_WAYPOINTS * 2)];



void motor_control_task(void *pvParameters) {
    while (1) {
        // 엔코더 세마포어만 기다림. (IMU 눈치 안 봄)
        if (xSemaphoreTake(encoder_sem, portMAX_DELAY) == pdTRUE) {
            // Motor_Task(요리사 B)는 encoder_sem 세마포어(주문서)가 올 때까지 여기서 대기함.
            // portMAX_DELAY 때문에 세마포어가 올 때까지 사실상 무한 대기함.
            // 대기 중인 Motor_Task는 Blocked 상태라서 CPU를 사용하지 않음.

            // 즉 Motor_Task는 RTOS에게
            // "encoder_sem 세마포어가 오면 나를 깨워줘"라고 요청한 상태가 됨.

            // 세마포어가 도착하는 시점은 ISR 안에서
            // xSemaphoreGiveFromISR(encoder_sem, &xHigherPriorityTaskWoken);
            // 코드가 실행될 때임.

            // 이 순간 encoder_sem 세마포어가 주어지고,
            // encoder_sem을 기다리던 Motor_Task가 실행 가능 상태(Ready)가 됨.

            // 그 다음 ISR(spi_post_callbac) 안의 portYIELD_FROM_ISR()는
            // "방금 깨어난 task가 현재 task보다 우선순위가 높으면
            // 인터럽트(spi_post_callbac)가 끝난 직후 바로 그 task로 전환해라"라고 RTOS에 요청함.

            // 그래서 ISR(spi_post_callbac)이 끝난 뒤 Motor_Task가 우선순위상 가장 높으면
            // 바로 CPU를 차지하고, xSemaphoreTake()가 pdTRUE를 반환해서
            // 이 if문 안으로 들어오게 됨.

            
            // 엔코더 계산 및 모터 출력 (여기서 Vq_left값이 모터로 들어감)
            encoder_to_vcc_cal(); 
        }
    }
}

static void spi_shared_cs_idle_init(void)
{
    gpio_config_t cs_cfg = {
        .pin_bit_mask = (1ULL << GPIO_NUM_8) | (1ULL << GPIO_NUM_9) | (1ULL << GPIO_NUM_10),
        .mode = GPIO_MODE_OUTPUT,
        .pull_up_en = GPIO_PULLUP_ENABLE,
        .pull_down_en = GPIO_PULLDOWN_DISABLE,
        .intr_type = GPIO_INTR_DISABLE,
    };

    gpio_config(&cs_cfg);

    gpio_set_level(GPIO_NUM_8, 1);   // LoRa CS 비선택
    gpio_set_level(GPIO_NUM_9, 1);   // 왼쪽 AS5048A CS 비선택
    gpio_set_level(GPIO_NUM_10, 1);  // 오른쪽 AS5048A CS 비선택
}

static void configure_console_log_filter(void)
{
    esp_log_level_set("*", ESP_LOG_NONE);
    esp_log_level_set("RTK_BRIDGE", ESP_LOG_INFO);
}

void app_main(void) {
    configure_console_log_filter();

    //세마포어 생성 (인터럽트와 태스크 동기화용)
    vTaskPrioritySet(NULL, 4); //메인문 태스크 우선순위 4
    imu_sem = xSemaphoreCreateBinary();

    spi_shared_cs_idle_init();

    // PID 초기화
    pid_init(&vel_ctrl, 0.35f, 0.002f, 0.0001f, 0.3f);//10.0f는 (속도pid결과값 = 목표피치각도 한계값, 지금은 최대 3도)임. p=0.43, i=0.001, limit=0.3f
    pid_init(&pitch_ctrl, 30.0f, 0.0f, 0.21f, 15.0f);//속도 pid에서 0.174라디안(10도)이 넘어왔을때 kp=100을 곱하면 17.4가 나옴(p=60 d=0.4, limit=15.0f)
    pid_init(&yaw_ctrl, 0.4f, 0.0f, 0.0001f, 2.0f);//목표요를 0.4rad(20도)로 했을때 kp=20을 곱하면 8이 나옴
    pid_init(&roll_ctrl, 2.0f, 0.10f, 0.01f, 150.0f);//v_limit=50.0f (장애물 높이 150mm까지 대응하도록 제한)
    pid_init(&wheel_l_ctrl, 0.10f, 0.000f, 0.000f, 2.0f);
    pid_init(&wheel_r_ctrl, 0.10f, 0.000f, 0.000f, 2.0f); 

    i2c_master_dev_handle_t imu_handle = imu_init();// IMU 디바이스 초기화 및 핸들 획득
    encoder_init();//encoder통신 초기설정 (내부에서 encoder_sem도 생성함)
    init_mcpwm_bldc();//mcpwm초기설정
    //init_hc06();///hc06 초기설정
    init_rx28();
    init_MPPI();
    init_gnss();
    init_lorartk();
    init_lidar();


    xTaskCreate(motor_control_task, "Motor_Task", 4096, NULL, 5, NULL);
    //motor_control_task라는 작업을 하는 Motor_Task라는 쓰레드(요리사b)가 채용되는(만들어지는) 코드임(Motor_Task라는 쓰레드는 우선순위 5임)
    //4096바이트(4KB)라는 ram메모리공간(요리사b전용 배낭)을 할당해서 코드를 수행하게 됨.
    //즉 encoder_to_vcc_cal함수 안에서 선언한 float angle_l, float pure_l같은 변수와 prinf같은 도구가 이 메모리공간에 저장됨
    //if, while, cosf같은 명령어와 전역변수 current_vel, encoder_sem는 flash메모리에 저장됨
    xTaskCreate(rx28_task, "RX28_Task", 4096, NULL, 3, NULL);
    xTaskCreate(MPPI_Task, "MPPI_Task", 4096, NULL, 2, NULL);
    imu_timer_init();// imu 타이머 모듈 초기화 (200Hz 인터럽트 시작)
    encoder_timer_init();// 엔코더 타이머 모듈 초기화 (1KHz 인터럽트 시작)


    // 1KHz 엔코더 제어 및 WDT 방지 루프
    while (1) {
        // 인터럽트가 세마포어를 줄 때까지 대기 (200Hz 주기에 맞춰 실행됨)
        
        if (xSemaphoreTake(imu_sem, portMAX_DELAY) == pdTRUE) {
        //main문이 실행될때 기본적으로 시스템이 xTaskCreate를 수행하여 app_main라는 기본요리사(스레드)한명을 채용함(우선운위1)
        //세마포어가 도착했을때 app_main라는 기본요리사가 수행할 main함수 안에 xSemaphoreTake조건문을 작성했기 때문에
        //app_main라는 기본 요리사가 rtos에게 imu_sem라는 세마포어(주문서)가 오면 깨워달라고 요청하게됨

            //실제 I2C 통신 수행 (ISR 밖이므로 안전)
            imu_data_cal(imu_handle);   

            if (fabsf(current_pitch) > (25.0f * M_PI / 180.0f)) {
                targetvel_vel = 0.0f;
                target_yaw_diff = 0.0f;

                Vq_left = 0.0f;
                Vq_right = 0.0f;

                vel_ctrl.err_sum = 0.0f;
                pitch_ctrl.err_sum = 0.0f;
                yaw_ctrl.err_sum = 0.0f;
                wheel_l_ctrl.err_sum = 0.0f;
                wheel_r_ctrl.err_sum = 0.0f;
                continue;
            }
    
            //*****gnss웨이포인트관련 함수코드 작성한뒤 그 안에서 station_packet[], station_packet_len 채우기
            //*****또한 그 함수 안에서 마지막에 station_packet_ready를 1로 해줘야함
            //*****기지국 RTCM 보정값은 LoRa로 받아서 ESP32가 UM982로 전달함.
            //*****UM982는 RTCM을 이용해 RTK 위치를 계산하고, GGA 문장으로 현재 위도/경도를 ESP32에 보냄.
            //*****ESP32는 GGA를 받을 때 update_gnss_position()을 호출해서 gnss_x, gnss_y를 갱신함.
            //*****MPPI 주기가 10Hz이므로, UM982 GGA 출력도 10Hz로 맞추는 게 좋음.
            //*****단, 현재 UM982 10Hz 출력 설정은 아직 안 함.
            if (station_packet_ready) {
                gnss_receive_complete(station_packet, station_packet_len);
                //station_packet는 웨이포인트 패킷 데이터 배열
                //station_packet_len 패킷길이. ex) 패킷 = [3, lat0, lon0, lat1, lon1, lat2, lon2]이면 station_packet_len는 7임
                station_packet_ready = 0;
            }

            //convert_station_waypoints_to_local_xy 함수에서 station_waypoint_ready가 1이 됨
            //즉 웨이포인트가 로컬좌표로 변환 완료되면 station_waypoint_ready가 1이 됨
            if (station_waypoint_ready) {
                waypoint_start();
                station_waypoint_ready = 0;
            }

            //data_tx();   

            if (current_roll > -0.5f && current_roll < 0.5f) {
                current_roll = 0.0f;
            }

            //roll_adj_mm = pid_calculate(&roll_ctrl, 0.0f, current_roll, 0.005f);// rx28제어할거면 주석해제//////////////////////////////////////////

            static float target_pitch = 0.0f;   


            // 속도 제어 루프 -> 목표 피치 결정
            if (vel_calc_flag == 1) {

                if (fabsf(targetvel_vel) != 0.0f) {
                    vel_ctrl.err_sum = 0.0f;
                }

                target_pitch = pid_calculate(&vel_ctrl, targetvel_vel, current_vel, 0.01f);//목표속도0. 나중에 hc06으로 받아와야함
                static float smoothed_target_pitch = 0.0f;
                //Low Pass Filter
                // 이전 목표치 95% + 새로운 목표치 5% (미친듯한 진동을 쫀득하게 흡수함)
                // 피치pid만 했을때는 진동이 없지만 속도pid를 넣으면 발작하는 이유는 피치pid의 d항에 의해 속도pid에서 새로운 목표각도를 넘기면 
                // 피치pid의 d항이 0.01초만에 오차가 확 변했다라고 판단하고 전압이 팍팍변해서 진동함
                // 그래서 속도pid를 포함했을때 속도pid에 의해 새로운 목표각도가 들어와도 확 꺽지말고 과거의 목표각도를 95%유지하고
                // 새로들어온 목표각도를5%만 반영해서 천천히 목표각도까지 오르도록함.
                smoothed_target_pitch = (0.95f * smoothed_target_pitch) + (0.05f * target_pitch);

                target_pitch = smoothed_target_pitch;

                vel_calc_flag = 0;
            }

            // 피치 및 요 PID 계산 (순수 보정 전압)
            //float p_out = pid_calculate(&pitch_ctrl, target_pitch, current_pitch, 0.005f); //피치pid의 목표피치를 0으로 하고 안정화되면 아 주석 pid값 맞추기
            float p_out = pid_calculate(&pitch_ctrl, target_pitch, current_pitch, 0.005f);

            float yaw_wheel_ref = target_yaw_diff * WHEEL_BASE / (2.0f * WHEEL_RADIUS);

            float wheel_l_out = pid_calculate(&wheel_l_ctrl, yaw_wheel_ref, omega_l_meas, 0.005f);
            float wheel_r_out = pid_calculate(&wheel_r_ctrl, yaw_wheel_ref, omega_r_meas, 0.005f);

            float pure_l = p_out + wheel_l_out;
            float pure_r = p_out - wheel_r_out;

            float MOTOR_V_MIN = 0.10f; // 모터가 꿈쩍하기 시작하는 최소 전압

            float MOVE_BOOST_V = 0.0f;   // 전진/후진 정지마찰 보상 전압
            float TURN_BOOST_V = 0.05f;   // 회전 정지마찰 보상 전압

            if (fabsf(targetvel_vel) > 0.02f) {
                if (pure_l > 0.0f) pure_l += MOVE_BOOST_V;
                else if (pure_l < 0.0f) pure_l -= MOVE_BOOST_V;

                if (pure_r > 0.0f) pure_r += MOVE_BOOST_V;
                else if (pure_r < 0.0f) pure_r -= MOVE_BOOST_V;
            }

            if (fabsf(target_yaw_diff) > 0.03f) {
                if (pure_l > 0.0f) pure_l += TURN_BOOST_V;
                else if (pure_l < 0.0f) pure_l -= TURN_BOOST_V;

                if (pure_r > 0.0f) pure_r += TURN_BOOST_V;
                else if (pure_r < 0.0f) pure_r -= TURN_BOOST_V;
            }

            static int hold_sign_l = 0;
            static int hold_sign_r = 0;

            float STICK_V = 0.18f;
            float CMD_ON  = 0.005f;
            float CMD_OFF = 0.001f;

            if (fabsf(targetvel_vel) < 0.02f &&
                fabsf(target_yaw_diff) < 0.03f &&
                fabsf(current_vel) < 0.03f) {

                if (pure_l > CMD_ON) hold_sign_l = 1;
                else if (pure_l < -CMD_ON) hold_sign_l = -1;
                else if (fabsf(pure_l) < CMD_OFF) hold_sign_l = 0;

                if (pure_r > CMD_ON) hold_sign_r = 1;
                else if (pure_r < -CMD_ON) hold_sign_r = -1;
                else if (fabsf(pure_r) < CMD_OFF) hold_sign_r = 0;

                Vq_left = pure_l + hold_sign_l * STICK_V;
                Vq_right = pure_r + hold_sign_r * STICK_V;
            } 
            else 
            {
                Vq_left = pure_l;
                Vq_right = pure_r;
            }

            static int plot_cnt = 0;
        }
    }
}

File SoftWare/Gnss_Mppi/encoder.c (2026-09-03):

#include <stdio.h>
#include "encoder.h"
#include "variable.h"
#include "esp_log.h"
#include "freertos/FreeRTOS.h"
#include "freertos/task.h"
#include "pwm.h"
#include <math.h>

// 다른 파일(main.c 등)에서도 사용해야 하는 변수들은 extern으로 선언합니다.
spi_transaction_t t_left;  // 왼쪽 엔코더용 트랜잭션
spi_transaction_t t_right; // 오른쪽 엔코더용 트랜잭션
uint16_t tx_data = 0xFFFF; // 패리티 주소 + 읽기/쓰기(RWn) + (PAR)0x3FFF(각도 주소) 이 정보를 합쳐서 0xFFFF라는 명령어 만듬 [cite: 563, 609]
uint16_t rx_data_left;     // 왼쪽 각도 데이터 빈 상자
uint16_t rx_data_right;    // 오른쪽 각도 데이터 빈 상자
encoder_handles_t enc_ctx;

spi_device_handle_t h_left;  
spi_device_handle_t h_right;

// 통신 완료 동기화를 위한 세마포어 핸들 선언 (WDT 에러 방지용)
SemaphoreHandle_t encoder_sem;

extern float omega_l_meas;
extern float omega_r_meas;

// void IRAM_ATTR spi_post_callback(spi_transaction_t *t) {
//     //void IRAM_ATTR는 spi_post_callback라는 인터럽트함수가 빠르게 실행될 수 있게 flash메모리에서 ram메모리로 꺼내두는 과정
//     // 통신 완료 인터럽트 콜백: 세마포어를 해제하여 app_main의 대기를 풀어줌
//     static BaseType_t xHigherPriorityTaskWoken = pdFALSE;
//     //xHigherPriorityTaskWoken는 요리사b(스레드)가 잠에서 깼는지에 대한 여부의 체크리스트변수. 초기값은 pdFALSE로 할당함.
//     xSemaphoreGiveFromISR(encoder_sem, &xHigherPriorityTaskWoken);
//     //rtos는 encoder_sem(세마포어)주문서와 imu_sem(세마포어)주문서를 기다리는 요리사(쓰레드) 각각의 우선순위를 확인하고 
//     //encoder_sem를 기다리는 요리사의 우선순위가 높기때문에 xHigherPriorityTaskWoken에 true를 적음
//     if (xHigherPriorityTaskWoken) {//요리사b(스레드)가 깨어있으면
//         portYIELD_FROM_ISR();//rtos가 요리작업대 사용자를 요리사a에서 요리사b로 바로 바꿈
//     }
// }

void IRAM_ATTR spi_post_callback(spi_transaction_t *t) {
    // SPI 통신 완료 인터럽트 콜백 함수.
    // 엔코더 SPI 읽기가 끝났다는 신호로 encoder_sem 세마포어를 Motor_Task에게 주는 함수.

    BaseType_t xHigherPriorityTaskWoken = pdFALSE;
    // 더 높은 우선순위 task가 깨어났는지 표시하는 변수.
    // 매번 ISR에 들어올 때 pdFALSE로 초기화해야 함.

    xSemaphoreGiveFromISR(encoder_sem, &xHigherPriorityTaskWoken);
    // encoder_sem 세마포어를 발행하는 코드임.
    // 이 순간 xSemaphoreTake(encoder_sem, ...)에서 자고 있던 Motor_Task가 Ready 상태가 됨.
    // 만약 깨어난 Motor_Task가 현재 실행 중이던 task보다 우선순위가 높으면
    // xHigherPriorityTaskWoken이 pdTRUE가 됨.

    if (xHigherPriorityTaskWoken == pdTRUE) {
        portYIELD_FROM_ISR();
        // ISR(spi_post_callback)이 끝난 직후, 
        // 방금 깨어난 고우선순위 task로 바로 전환하라고 RTOS에 요청함.
    }
}

static bool timer_on_alarm_cb(gptimer_handle_t timer, const gptimer_alarm_event_data_t *edata, void *user_ctx)
{//alarm_count가 1000에 도달하면 ESP32의 하드웨어 타이머 컨트롤러가 timer_on_alarm_cb이 함수를 호출함
    encoder_handles_t *handles = (encoder_handles_t *)user_ctx;
    
    // 왼쪽과 오른쪽 엔코더에 동시에 전송 큐를 삽입함
    spi_device_queue_trans(handles->left, &t_left, 0);
    spi_device_queue_trans(handles->right, &t_right, 0);
    
    return false;
}

void encoder_timer_init (void)
{
    gptimer_handle_t gptimer = NULL;//gptimer변수 선언 후 아래 코드부터 쭉 gptimer설정코드임
    gptimer_config_t timer_config = {
        .clk_src = GPTIMER_CLK_SRC_DEFAULT, // Select the default clock source
        .direction = GPTIMER_COUNT_UP,      // Counting direction is up
        .resolution_hz = 1 * 1000 * 1000,   // 1초에 타이머가 몇번 올라갈것인가
    };
    ESP_ERROR_CHECK(gptimer_new_timer(&timer_config, &gptimer));

    gptimer_alarm_config_t alarm_config = {
        .reload_count = 0,      // When the alarm event occurs, the timer will automatically reload to 0
        .alarm_count = 1000, // Set the actual alarm period, since the resolution is 1us, 1000은 1ms (1KHz)
        .flags.auto_reload_on_alarm = true, // Enable auto-reload function
    };
    ESP_ERROR_CHECK(gptimer_set_alarm_action(gptimer, &alarm_config));

    gptimer_event_callbacks_t cbs = { .on_alarm = timer_on_alarm_cb };
    //alarm_count가 1000에 도달해 알람이 울리면 timer_on_alarm_cb함수를 실행하겠다라는 내용을 cbs라는 구조체에 적음
    ESP_ERROR_CHECK(gptimer_register_event_callbacks(gptimer, &cbs, &enc_ctx));
    //cbs라는 구조체를 이용해 gptimer에게 등록하는 행위
    ESP_ERROR_CHECK(gptimer_enable(gptimer));
    // Start the timer
    ESP_ERROR_CHECK(gptimer_start(gptimer));
}

void encoder_init(void)//엔코더 초기설정
{
    // 세마포어라는 신호의 존재를 만들고 초기화
    encoder_sem = xSemaphoreCreateBinary();

    spi_bus_config_t buscfg = {
        .miso_io_num = 13,    
        .mosi_io_num = 11,    
        .sclk_io_num = 12,       
        .quadwp_io_num = -1,
        .quadhd_io_num = -1,
    };

    spi_device_interface_config_t devcfg = {
        .command_bits = 0,
        .address_bits = 0,
        .mode = 1,
        //엔코더데이터시트 11페이지를 보면 clk는 0부터 시작해서 CPOL = 0,
        //MOSI나 MISO 선에 있는 데이터 비트의 중심이 CLK의 내려가는선에 맞춰져있어서 CPHA = 1, 따라서 모드는 1임
        .clock_speed_hz = 10000000,//10MHz(spi통신박자)(엔코더 데이터시트 12페이지에 TCLK는 최소 100ns = 10MHz라고 되어있음)
        .queue_size = 7,
        .spics_io_num = 9, // 왼쪽 엔코더 CS 핀 [cite: 167]
        .clock_source = SPI_CLK_SRC_DEFAULT, 
        //clock_source 멤버는 SPI 통신 클럭을 생성하기 위해 어떤 뿌리(Source) 전원을 사용할지 결정하는 옵션
        // 시스템이 알아서 최적의 시계를 선택하도록 함
        .cs_ena_pretrans = 4,
        //엔코더 데이터시트 12페이지를 보면 mcu에서 CSn을 내리고난 후 첫번째 클럭신호가 rising이 되기까지의 시간이 최소 350ns라고 되어있음(tl)
        //.cs_ena_pretrans = 4,이 코드의 의미는 현재 10MHz이므로 1클럭당 100ns가 됨. 즉 100ns를 4번 더 보내는거니까 400ns만큼 기다림.
        .post_cb = spi_post_callback,// 통신 완료 인터럽트 콜백
    };

    // 오른쪽 엔코더 설정 (CS 핀만 다르게 설정, 나머지는 왼쪽과 동일)
    spi_device_interface_config_t devcfg_right = devcfg;
    devcfg_right.spics_io_num = 10; // 오른쪽 엔코더 CS 핀 (10번으로 가정)

    spi_bus_initialize(SPI2_HOST, &buscfg, SPI_DMA_CH_AUTO);
    spi_bus_add_device(SPI2_HOST, &devcfg, &h_left);
    spi_bus_add_device(SPI2_HOST, &devcfg_right, &h_right);

    //전송 구조체 세부 설정 (왼쪽)
    t_left.length = 16;
    t_left.tx_buffer = &tx_data;//0xFFFF라는 변수의 주소값 전달
    t_left.rx_buffer = &rx_data_left;//엔코더가 준 값이 rx_data_left변수에 저장됨

    //전송 구조체 세부 설정 (오른쪽)
    t_right.length = 16;
    t_right.tx_buffer = &tx_data;//0xFFFF라는 변수의 주소값 전달
    t_right.rx_buffer = &rx_data_right;//엔코더가 준 값이 rx_data_right변수에 저장됨

    // 콜백 함수에 두 핸들을 모두 전달하기 위해 구조체에 담음
    enc_ctx.left = h_left;
    enc_ctx.right = h_right;
}
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

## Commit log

2026-05-04 Sync encoder.c verbatim from local source
2026-05-04 Replace lidar.c with ROM printf debug version
    [lidar.c]
2026-05-19 Sync latest ESP32 Gnss_Mppi main code
2026-09-06 Add ground station code
2026-09-11 Update hardware STL assets and README assembly image
    [FP04-F2.STL, GM4108Motor_AS5048AEncoder_simplified.STL, HN07-N101.STL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]
2026-09-11 Move assembly image below README badges
